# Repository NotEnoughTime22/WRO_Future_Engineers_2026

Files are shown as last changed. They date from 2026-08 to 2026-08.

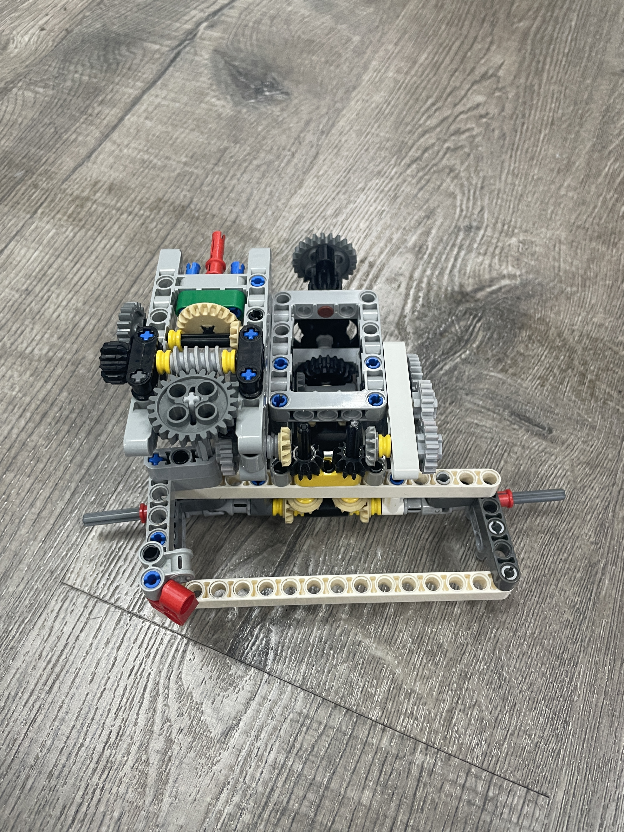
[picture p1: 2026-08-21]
Photos/First Prototype/Front side of first prototype chassis.JPG

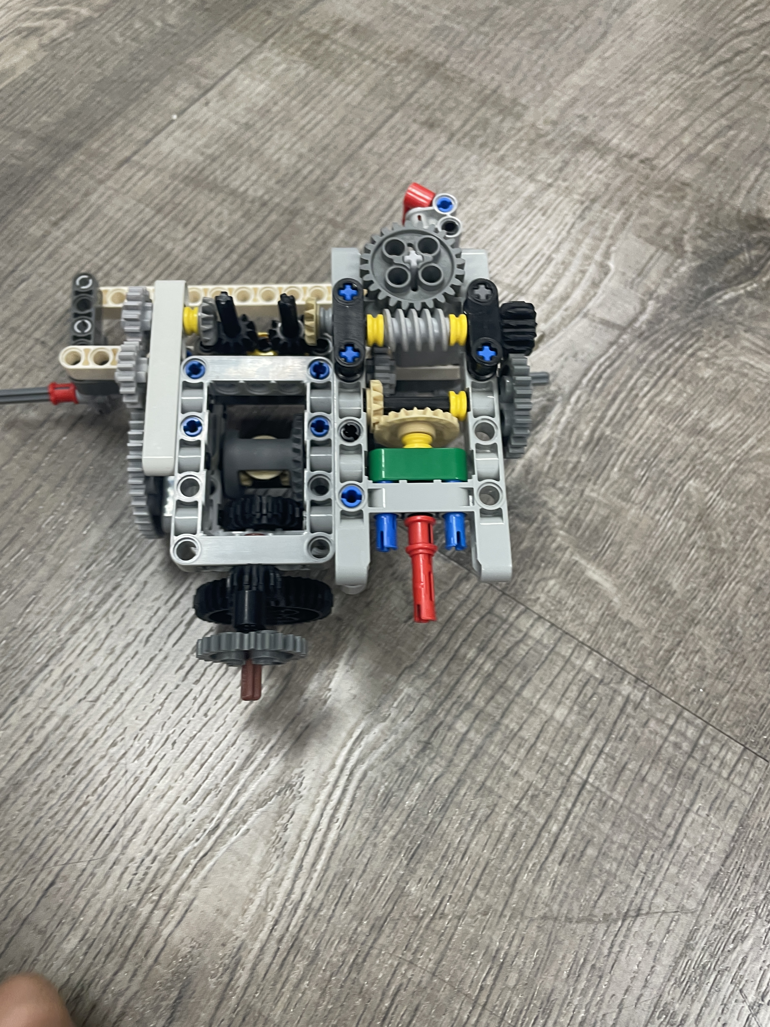
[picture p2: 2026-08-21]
Photos/First Prototype/Back side of first prototype chassis.JPG

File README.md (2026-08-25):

# SSTitans

This repository contains the complete engineering materials for SSTactical's self-driving vehicle competing in the WRO Future Engineers 2026 season. It documents the hardware design, software architecture, machine learning pipeline, and control algorithms that enable the robot to navigate an autonomous track, detect gaps, perform parallel parking, and recognise visual markers.

## Repository Structure

* `Codes/` contains the Arduino sketches that run on the EvolutionX1 microcontroller. `Open_Code.ino` implements the primary autonomous driving logic including PD heading control, gap navigation, square traversal, and parallel parking. `Obstacle_code.ino` extends the gap navigation with colour-based obstacle avoidance using MaixCam detections.
* `Documents/` contains the official WRO Engineering Journal (PDF) maintained by the team throughout the season, documenting design decisions, testing results, and progress.
* `Libraries/` contains the custom C++ libraries written to interface with the vehicle hardware. These include motor control, sensor abstraction, pin mapping, and the core Evo system library.
* `ML/` contains the machine learning pipeline for visual object detection running on the MaixCam. This includes the trained YOLOv5 model, the inference script, training annotations, and configuration files.
* `Models/` contains 3D printable STL files for custom mounts and brackets used in the vehicle construction.
* `Photos/` contains documentation photographs of the team and the vehicle at various stages of development.
* `Videos/` contains demonstration videos of the robot performing both the open and challenge runs of the competition. 

## Hardware Components

The vehicle is built around the following electromechanical components:

| Component | Model | Quantity | Purpose |
| :--- | :--- | :--- | :--- |
| Microcontroller | EvolutionX1 (ESP32-S3) | 1 | Central processing unit running all control logic |
| Drive Motor | EvoMotor300 | 1 | Provides propulsion via rear axle |
| Steering Servo | GeekServo 360 Grey | 1 | Controls front wheel steering angle |
| Camera | MaixCam | 1 | Runs YOLOv5 inference for visual detection |
| Distance Sensors | VL53L0X (Time of Flight) | 4 | Obstacle and gap detection (front, back, left, right) |
| Compass / IMU | BNO055 | 1 | Provides absolute heading for navigation |
| I2C Multiplexer | TCA9548A | 1 | Routes I2C signals to multiple sensors on shared bus |
| IO Expander | SX1506 | 1 | Provides PWM outputs for motor control |
| Battery | Panasonic NCR18650B | 2 | Power supply for all electronics |

### Wiring and Pin Assignments

The EvolutionX1 exposes four Lego sensor ports (S1 through S4) and four motor ports (M1 through M4). The pin mapping is defined in `Libraries/X1pins (1).h`. Each sensor port provides two GPIO pins for UART or I2C communication. Each motor port provides two PWM channels through the SX1506 IO expander and two tachometer pins for quadrature encoder feedback.

The I2C bus is multiplexed through the TCA9548A with the following channel assignments:

| I2C Channel | Device |
| :--- | :--- |
| 0 | IMU (BNO055) on I2C1 |
| 1 | ToF Right (VL53L0X) on I2C2 |
| 2 | ToF Left (VL53L0X) on I2C3 |
| 3 | ToF Front (VL53L0X) on I2C4 |
| 4 | ToF Back (VL53L0X) on I2C5 |
| 5 | SX1506 IO Expander |
| 6 | MPU9250 (reserved) |
| 7 | SSD1306 OLED Display |

The MaixCam communicates with the microcontroller over I2C5 at address `0x24`, transmitting detected object data in a binary protocol.

## Software Architecture

The software is split across two processors.

### Microcontroller (EvolutionX1 / ESP32-S3)

The main firmware is written in C++ using the Arduino framework. The entry point is `Codes/Open_Code.ino`. The architecture consists of:

**Hardware Abstraction Layer** provided by the custom libraries in `Libraries/`:

* `Evo (1).h / .cpp` wraps the core EVO singleton class. It manages I2C bus initialisation, TCA9548A channel selection, battery voltage reading via the BQ25887 charger IC, buzzer tone generation, and SSD1306 OLED display output.
* `EV3 Motor (1).h / .cpp` implements the `EV3Motor` class. Each motor instance is bound to a port (M1 to M4) and controls direction via the SX1509 IO expander PWM outputs. Encoder feedback is read through the `ESP32Encoder` library. A FreeRTOS background task runs a proportional controller for braking and target-position modes. The motor supports four states: RUN (continuous speed), TARGET (drive to encoder position), BRAKE (active hold), and COAST (passive stop).
* `VL53L0X Library.h / .cpp` wraps the Adafruit VL53L0X driver. Each sensor is assigned to an I2C multiplexer channel. The `getDistance()` method selects the correct channel, performs a ranging measurement, and returns the distance in millimetres. Readings below 10mm are treated as invalid and replaced with a sentinel value of 8191.
* `EV3 Sensor Port (1).h / .cpp` implements the Lego UART sensor protocol. It handles sensor discovery, mode negotiation, baud rate switching, and continuous data streaming using a dedicated FreeRTOS task pinned to core 0.
* `X1pins (1).h` defines all GPIO pin mappings, I2C addresses, and enumerations for motor ports, sensor ports, and I2C channels.

**Control Layer** implemented directly in `Open_Code.ino`:

The control layer uses a PD (Proportional-Derivative) controller to maintain heading while driving. The key parameters are:

* `KP_HEADING = 1.7` proportional gain
* `KD_HEADING = 0.0` derivative gain (currently disabled)
* `DRIVE_SPEED = 3000` constant motor speed in encoder degrees per second
* `STRAIGHT_DEGREES = 6000` encoder degrees per square edge
* `SERVO_RATIO = 2.33` maps wheel degrees to servo degrees
* `MAX_WHEEL_ANGLE = 35` maximum steering angle in degrees

The `applySteering()` function converts a desired wheel angle into a servo command by multiplying by the servo ratio and offsetting from the centre position (180 degrees). The result is constrained to the 0 to 360 degree range of the GeekServo 360.

Heading is read from the BNO055 IMU using `readHeadingSafe()`, which performs two attempts and falls back to the last valid reading if both fail. This prevents sudden heading jumps from corrupting the controller. All headings are normalised to the 0 to 360 degree range, and heading error is computed as the shortest angular distance (clamped to plus or minus 180 degrees).

The `snapHeading45()` function rounds any heading to the nearest 45 degree increment (0, 45, 90, 135, 180, 225, 270, 315). This is used throughout the navigation logic to ensure the robot only drives along axis-aligned and diagonal directions, which simplifies the track geometry.

### Driving Modes

The firmware implements three primary driving behaviours, selected in `setup()`:

**1. Square Traversal (`squareWithPDSteering`)**

Drives a square path of a given number of sides. The robot holds a constant speed and uses PD steering to maintain the current target heading. After travelling `STRAIGHT_DEGREES` encoder counts, the target heading is rotated by 90 degrees and snapped to the nearest 45 degree increment. The process repeats until all sides are completed, then the motor brakes and the servo centres.

**2. Gap Navigation (`driveAndTurnOnGaps`)**

This is the primary autonomous driving mode for the competition track. The robot drives forward while continuously monitoring the left and right Time of Flight sensors. Gap detection uses a `ToFSmoother` struct that maintains a 5-sample rolling average filter on each sensor. A gap is confirmed when either:

* The filtered distance exceeds `GAP_THRESHOLD_MM` (650mm), or
* The distance increases by more than 150mm between consecutive readings

Both conditions must persist for `GAP_CONFIRM_SAMPLES` (4) consecutive readings to avoid false triggers. A cooldown timer of `TURN_COOLDOWN_MS` (700ms) prevents multiple turns at the same intersection.

When a gap is confirmed, the robot computes the new target heading by rotating 90 degrees left or right. If gaps are detected on both sides, the robot turns toward the side with the larger clearance (plus a 100mm margin). The turn is executed while the motor continues running, using IMU heading control. The turn completes when the heading error drops below `TURN_COMPLETE_ERROR` (8 degrees). After turning, the robot drives forward for `POST_TURN_DISTANCE` (1000 encoder degrees) to clear the intersection before resuming gap detection.

A front-facing safety check stops the motor if an obstacle is detected within 80mm during a turn, then immediately resumes driving after a 150ms pause.

**3. Parallel Parking (`parallelParkWithTOF`)**

Executes a multi-phase parallel parking manoeuvre using all four ToF sensors:

* Phase 1: If the right sensor reads more than 100mm, the robot is too far from the wall. It angles 45 degrees toward the wall and drives in small increments until the diagonal distance (right distance multiplied by sin(45)) drops below 100mm.
* Phase 2: The robot turns to run parallel to the wall and drives forward until the front sensor reads less than 200mm.
* Phase 3: The robot angles 45 degrees away from the wall and drives a fixed distance of 1000 encoder degrees to pull alongside the parking spot.
* Phase 4: The robot straightens and drives forward until the front sensor reads less than 100mm, then completes with a final 200-degree adjustment.

**4. Obstacle Avoidance with Colour Detection (`driveAndTurnOnGapsWithColourAvoidance`)**

The `Obstacle_code.ino` sketch extends the gap navigation system with colour-based obstacle avoidance. This mode integrates MaixCam YOLO detections with the ToF-based gap navigation to avoid coloured obstacles (green and red objects) placed on the track.

The colour avoidance system uses a finite state machine with six states:

* `COLOR_NONE`: Normal driving mode. The robot monitors for colour detections while performing gap navigation.
* `COLOR_TURN_OUT`: When a coloured object is detected, the robot turns 45 degrees away from the obstacle (left for green, right for red) while continuing to drive forward.
* `COLOR_DRIVE_OUT`: After completing the turn, the robot drives forward until the object is no longer detected for 350ms AND the robot has travelled at least 500 encoder degrees away from the obstacle.
* `COLOR_TURN_BACK`: The robot turns 90 degrees back toward the original heading to align parallel to the track.
* `COLOR_DRIVE_BACK`: The robot drives forward the same distance it travelled outward to return to the original path.
* `COLOR_RETURN_HEADING`: The robot turns back to the original heading and resumes normal gap navigation.

The system validates detections using three criteria: the object class must be green (ID 1) or red (ID 2), the bounding box area must exceed 100 pixels, and the confidence score must be above 0.50. Objects detected too low in the image (y-center above 160 pixels) are ignored to avoid false positives from distant obstacles.

A retrigger cooldown of 1000ms prevents the robot from repeatedly avoiding the same object. The colour avoidance behaviour takes priority over gap turns, ensuring the robot always responds to obstacles before considering intersection navigation.

### MaixCam (Vision Processor)

The MaixCam runs a Python script (`ML/main.py`) that performs real-time object detection using a YOLOv5 model. The model was trained on 147 (Based on 25 Aug, we are still training, final model should include 1000+) annotated images and compiled into a `.mud` and `.cvimodel` format for the Maix hardware accelerator.

The detection loop operates as follows:

1. Capture a frame from the camera at the model's input resolution (224x224, 3 channels).
2. Run YOLOv5 inference with a confidence threshold of 0.5 and IoU threshold of 0.45.
3. If objects are detected, encode their bounding boxes (x, y, width, height, class ID, confidence score) into a binary payload using the `encode_objs()` function. Each object occupies 14 bytes in the payload.
4. Transmit the payload to the EvolutionX1 microcontroller over I2C5 at address `0x24`.
5. Draw red bounding boxes and labels on the live preview displayed on the MaixCam screen.

The model configuration in `ML/app.yaml` identifies it as "Detector 317447" version 1.0.0, generated by MaixHub. The training report in `ML/report.json` shows the model converged to a final loss of approximately 0.68 over 100 epochs with a learning rate schedule decaying from 0.001 to 0.0001.

## 3D Printed Models

The `Models/` directory contains two STL files for custom mechanical parts:

* `EVO Brick Model.stl` is the enclosure case that holds the EvolutionX1 microcontroller brick in place on the chassis.
* `VL53L0X Lego Mount Model.stl` is a bracket that mounts a VL53L0X Time of Flight sensor to the Lego Technic frame at the correct height and angle.

## Setup Instructions

### Prerequisites

* Arduino IDE with ESP32 board support installed
* Board selection set to ESP32-S3
* USB cable capable of data transfer

### Library Installation

All libraries must be installed before compiling the code.

1. Install each `.zip` file found in the external libraries folder by opening the Arduino IDE, navigating to Sketch, then Include Library, then Add .ZIP Library, and selecting each archive.
2. Install the custom Evo library by selecting the `Evo.zip` archive through the same Add .ZIP Library menu.
3. All libraries are required for the code to compile and run correctly.

### Uploading the Firmware

1. Open `Codes/Open_Code.ino` in the Arduino IDE.
2. Verify that the board is set to ESP32-S3 under the Tools menu.
3. Select the correct serial port for the EvolutionX1.
4. Click Upload to flash the firmware to the microcontroller.

### Deploying the MaixCam Model

1. Copy the contents of the `ML/` directory to the MaixCam's SD card or internal storage.
2. Ensure the `model_317447.mud` and `model_317447.cvimodel` files are present alongside `main.py`.
3. Power on the MaixCam and the script will begin executing automatically.

## Pre-Run Checklist

### Software Verification

* Confirm the Arduino IDE board selection is set to ESP32-S3.
* Verify that all sensors have been calibrated for the competition venue lighting and surface conditions.
* Ensure the MaixCam model is loaded and the I2C address matches the microcontroller configuration.

### Hardware Inspection

* Check that every wire is connected to the correct terminal and that no loose connections exist.
* Test all four ToF sensors for consistent readings and replace any that return erratic values.
* Verify the IMU provides stable heading readings without drift.
* Inspect all structural parts for tightness and replace any cracked or weakened components.
* Ensure the wheels are securely fastened to the axles and do not wobble.
* Test the steering servo for smooth operation across the full 0 to 360 degree range.
* Confirm the battery voltage is above the minimum operating threshold.

### Robot Placement

* Place the robot on the track in a straight orientation aligned with the intended starting direction.
* The initial heading is captured during setup and used as the reference for all subsequent navigation.

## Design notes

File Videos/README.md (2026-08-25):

This folder contains videos of the robot performing the open and challenge stages of the category

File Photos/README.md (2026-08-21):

This folder contains pictures of the robot from first prototype to final design.

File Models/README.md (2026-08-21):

This is a collection of 3d models used for 3d printing during this project.

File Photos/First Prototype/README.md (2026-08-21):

This folder of images is dedicated to the first prototype and its variations.

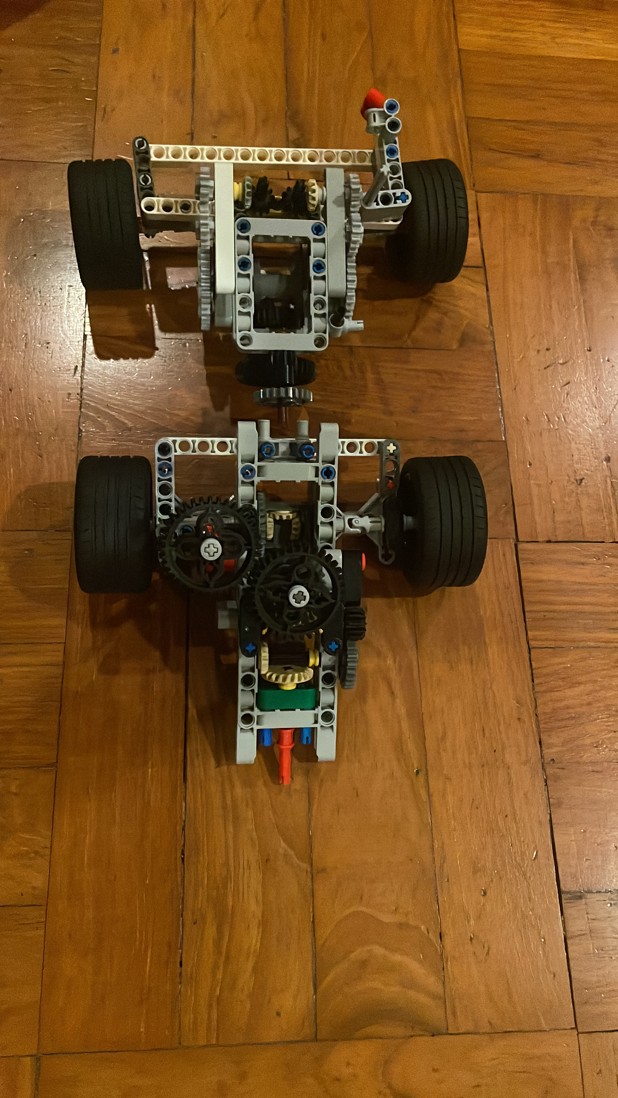
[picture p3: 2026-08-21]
Photos/First Prototype/Comparison of first and second(unfinished) chassis.jpg

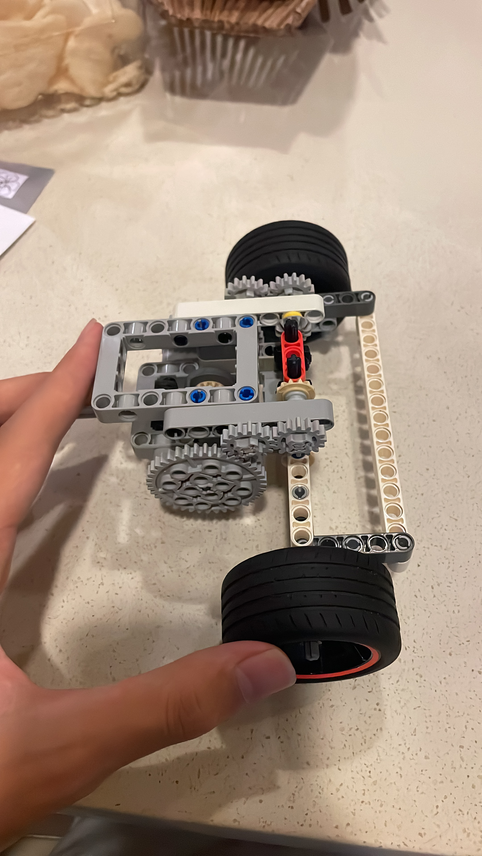
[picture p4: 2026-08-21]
Photos/First Prototype/Right side of unfinished first prototype chassis.jpg

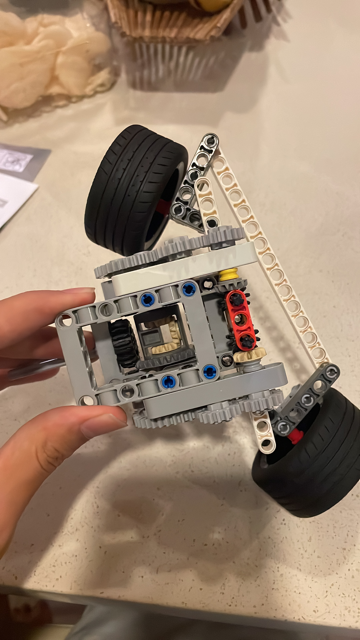
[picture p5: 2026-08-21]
Photos/First Prototype/Maximum turn angle of unfinished first prototype chassis.jpg

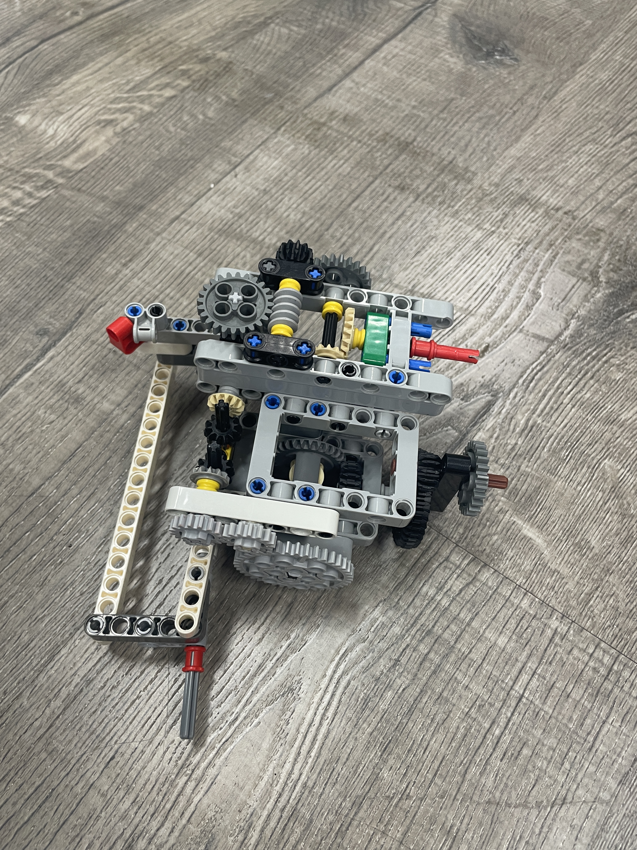
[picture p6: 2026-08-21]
Photos/First Prototype/Left side of first prototype chassis.JPG

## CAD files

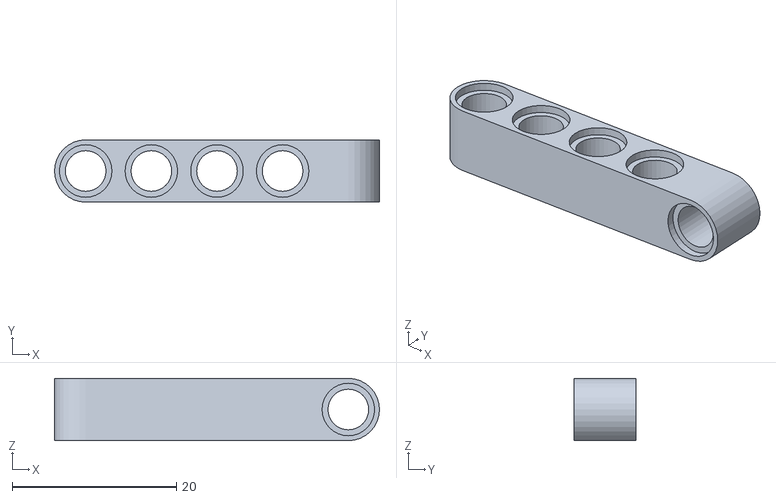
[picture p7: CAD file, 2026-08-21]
Models/Failed Files/weird_5_hole.stl
39.6 x 7.60 x 7.60

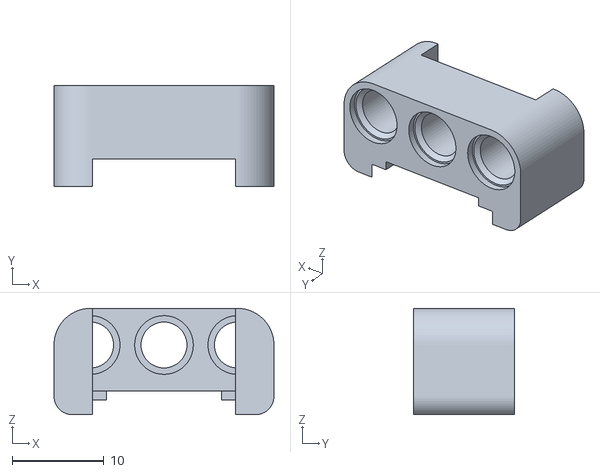
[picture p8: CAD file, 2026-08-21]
Models/VL53L0X Lego Mount Model.stl
24.0 x 11.0 x 11.6

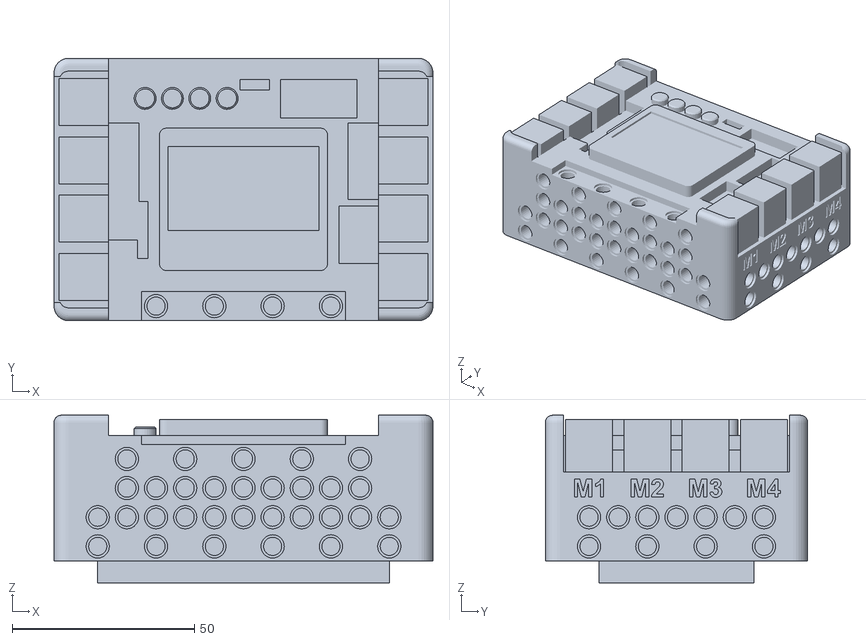
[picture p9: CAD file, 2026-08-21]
Models/EVO Brick Model.stl
104.0 x 72.0 x 46.0

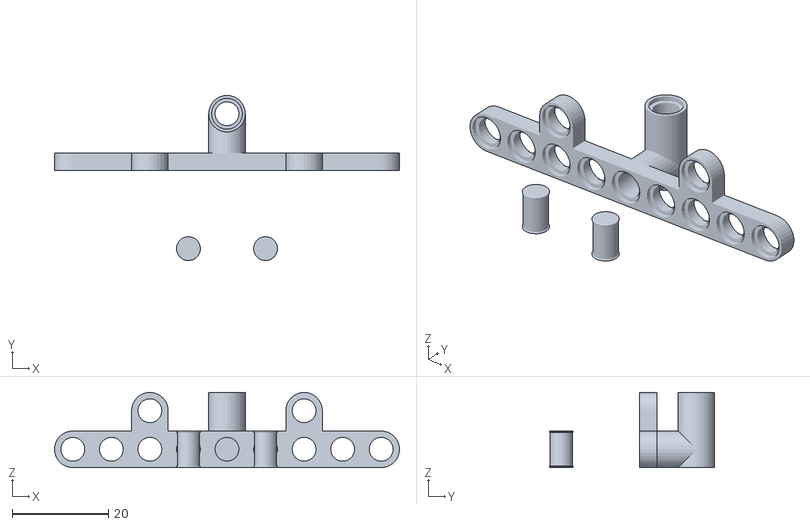
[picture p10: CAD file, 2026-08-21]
Models/Failed Files/weird_axel_thingy.stl
71.6 x 34.3 x 15.6

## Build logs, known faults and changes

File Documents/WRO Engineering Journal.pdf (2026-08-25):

# WRO Engineering Journal

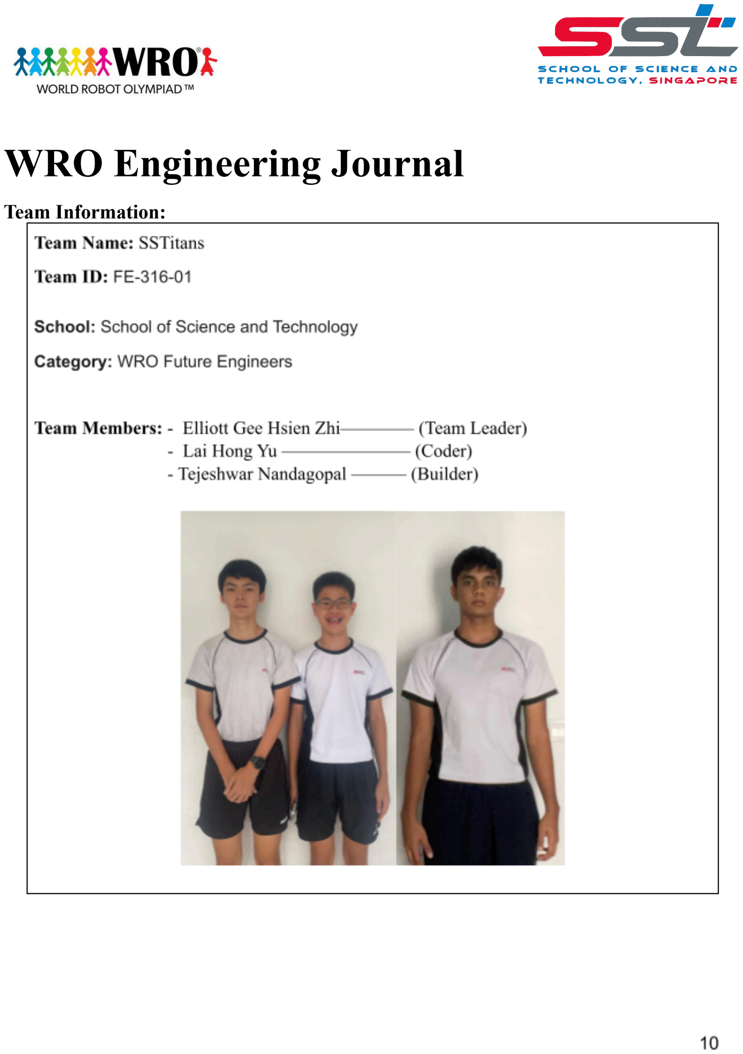
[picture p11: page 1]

Team Information:

## Contents

- Hardware Overview
- Drivetrain
- Components
- Strategy
- Code

### Hardware Overview

Table of Components used by the robot:

Part Name | Model | Quantity | Others
GeekServo | GeekServo360Grey | 1
EvoMotor | EvoMotor300 | 1
Time of Flight | VL53L0X | 4
Camera | MaixCam | 1
Microcontroller | ESP32S3 | 1
12C Microplexer | TCA9548A | 1
IO Multiplexer | SX1506 | 1
IMU | BNO055 | 1
Battery | NCR18650B | 2

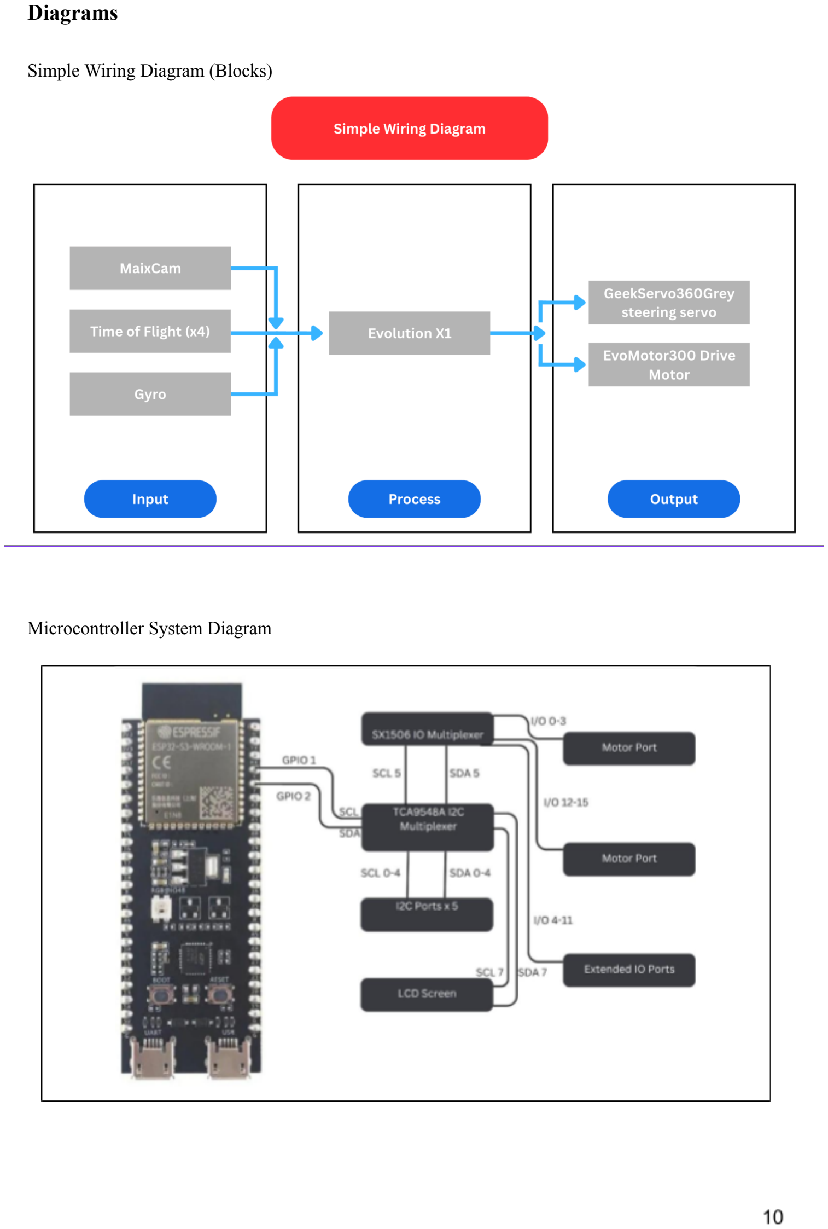
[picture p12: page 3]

Diagrams

Simple Wiring Diagram (Blocks)

Microcontroller System Diagram

### Drivetrain

Chassis Design
To build our chassis, we used LEGO parts, as they were light yet able to withstand the weight of the EvolutionX1 Brick. LEGO parts made it easy for us to prototype our models, as we built numerous prototype chassis before landing on the final design. We also made use of 3D-modelled holders for our sensors with LEGO compatibility; thus, it is easy to install and replace. We also designed it with a tight turning circle in mind, and as such we chose a 4WD & 4-wheel steering chassis.

Here are some photos of the vehicle:

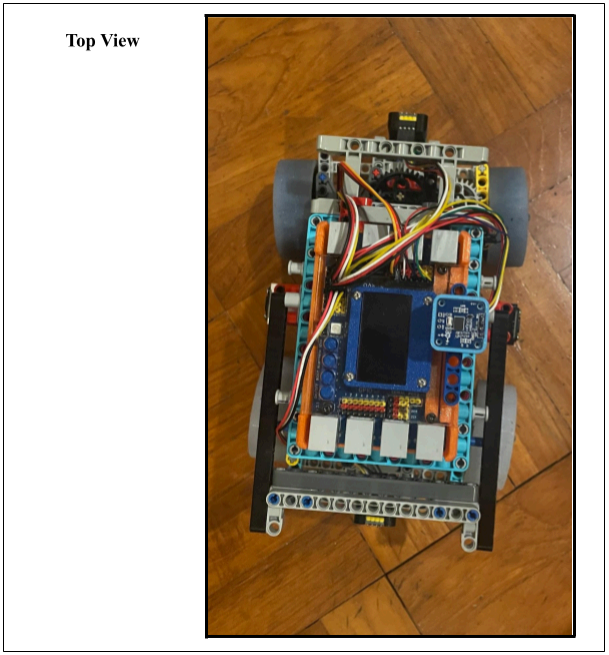
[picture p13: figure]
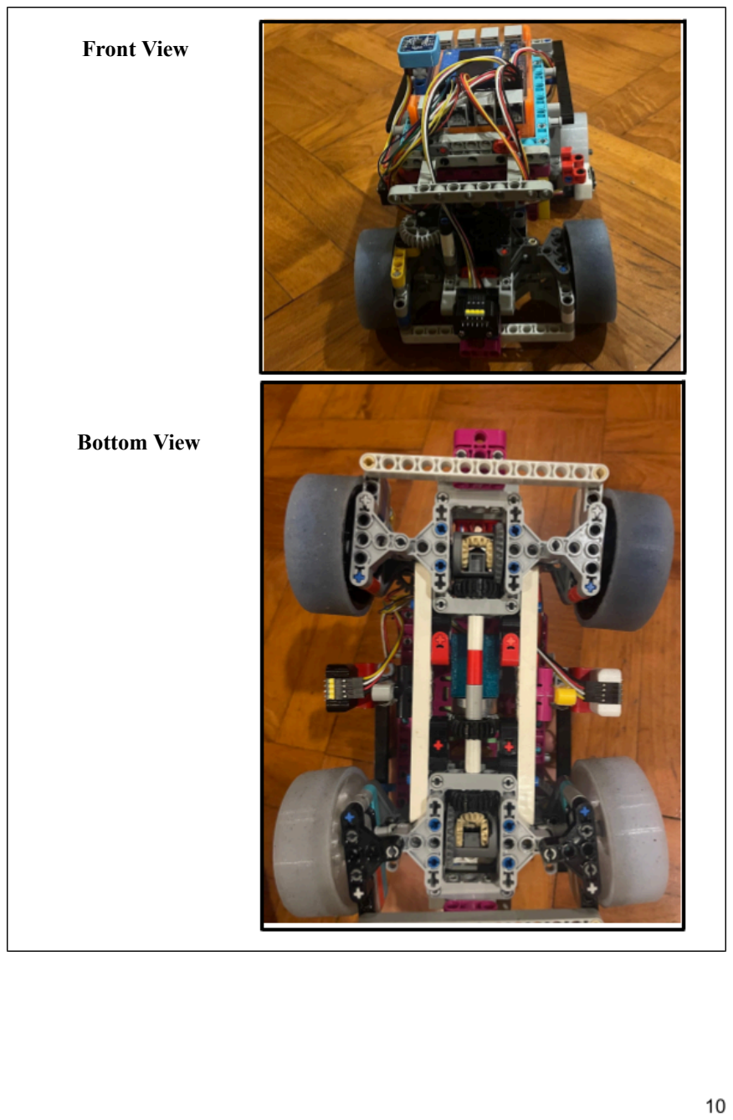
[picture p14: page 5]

Front View

Bottom View

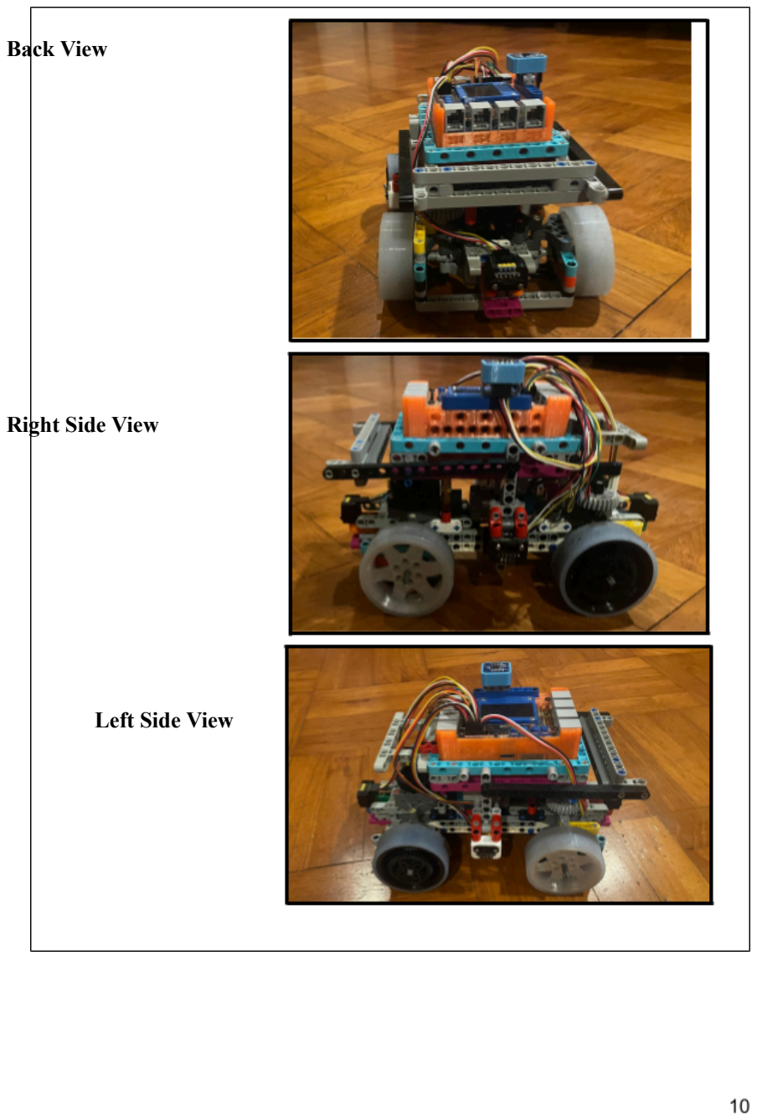
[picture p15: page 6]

Back View

Right Side View

Left Side View

Motors

The motors we have chosen to use as a part of our bot are the EvoMotor300, which has a balance of speed and torque compared to the Evomotor100, which has more torque at the cost of speed. The other reasons we chose this motor were the size limit and the navigation challenge. We felt that having a smaller bot would be easier to navigate through the blocks, so we chose to go for compactness.

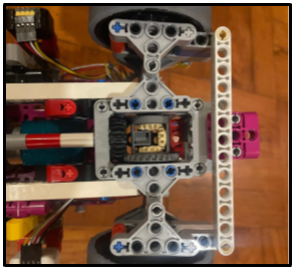
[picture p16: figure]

Differential

The drive motor is connected to two differential gears at the bottom of the bot. Having a differential allows the robot's wheel to turn at different speeds, which is crucial to achieving smooth turning.

Steering

For our steering, our team has chosen a geared ackermann steering mechanism, which is a common steering mechanism used by many people in the world, while we also wanted to go for a design of a 4 wheel drive and 4 wheel steering car. This 4 wheel steering system allows us to have a much tighter turning circle, giving us extra manoeuvrability. Moreover, the ackermann steering geometry allows the inner wheels to turn more than the outer ones, providing better and more precise turning. This is due to the inner wheels needing to make a tighter arc than the outer wheels.

### Components

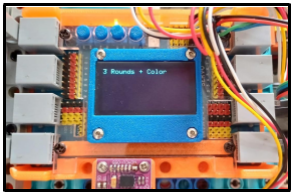
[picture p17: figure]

Evolution X1

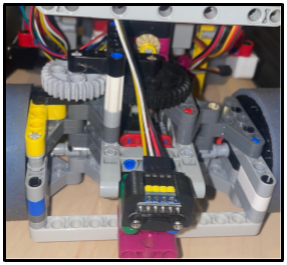
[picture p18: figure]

The Evolution X1 Controller Platform is a versatile and powerful development board designed to seamlessly integrate with the LEGO EV3 Mindstorms ecosystem. Built around the robust ESP32-S3 microcontroller, this platform offers a unique combination of connectivity, performance and flexibility. Below are the key features of Exolution X1, and these are some reasons why we chose it.

Key Features:

- EV3 Mindstorms Compatibility
The controller is equipped with specialised connectors that enable seamless connection and control of the EV3 Mindstorms motors and sensors. This compatibility allows us to utilise the existing EV3 components while taking advantage of the advanced features of the ESP32-S3. Although we did not use these features in this robot, they are useful to have.
- Extended GPIO Pinouts
In addition to EV3 connectors, the platform offers an extensive set of GPIO pinouts. These pinouts allow us to connect various third-party sensors and actuators, broadening the scope for customisation and experimentation.
- Powerful ESP32-S3 Microcontroller
The platform is powered by the ESP32-S3 microcontroller, which stands out for its great performance, energy efficiency, and versatile features. It offers dual-core processing, built-in Wi-Fi and Bluetooth, and plenty of peripheral options, making it a flexible and reliable choice for all kinds of applications.
- User-Friendly Development Environment
The platform supports popular development environments such as Arduino, MicroPython, and Espressif's IDF, providing a user-friendly and familiar programming experience. It is also backed by comprehensive documentation and strong community support, enhancing the development process.

Time of Flight (ToF)

A Time of Flight (ToF) sensor measures distance by emitting a light signal, typically infrared, and calculating the time it takes for the signal to travel to an object and return. This time is then used to determine the precise distance to the object.

We selected it primarily for its precise distance measurement capabilities. ToF sensors can measure distances with exceptional accuracy—often down to the millimetre—making them ideal for applications that demand precise measurements. They can also measure over a wide range, from just a few centimetres to several metres, depending on the model.

Another advantage is their fast response time. ToF sensors deliver rapid measurements, enabling real-time functions such as gesture recognition, object tracking, and obstacle detection. Since they operate at the speed of light, they can perform distance calculations extremely quickly, providing low-latency data essential in dynamic environments.

Finally, ToF sensors are easy to integrate. They typically use standard communication protocols like I²C or SPI, making them straightforward to connect with microcontrollers and other digital systems. Some models even feature built-in processing, simplifying their use in more complex implementations.

Gyroscope (IMU)

For our gyroscope, we chose the BNO-055. This is a compact 9-axis sensor that combines an accelerometer, gyroscope, magnetometer, and a 32-bit microcontroller with sensor fusion software.

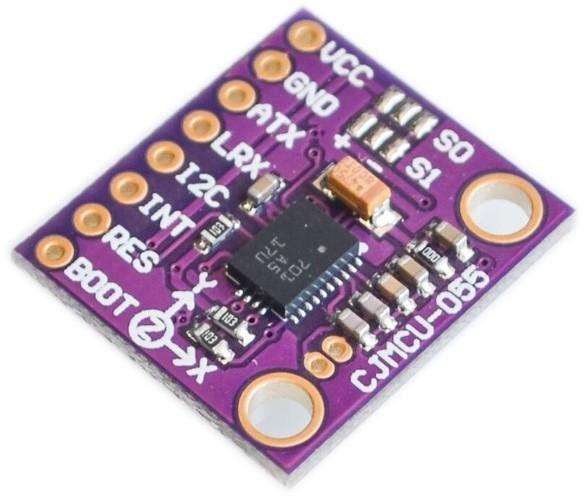
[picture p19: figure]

Our main reasons for choosing this component are, firstly, that by integrating an accelerometer, gyroscope, magnetometer, and microcontroller into a single module, it reduces the need for multiple separate sensors, thus reducing the overall data processing requirements and saving memory. Secondly, its compact form also minimises physical space usage, making it ideal for our compactly designed robot.

MaixCam Camera

The MaixCAM is a compact, Linux-based AI vision camera that can run real-time computer-vision models directly on its onboard processor. It supports object detection with models such as YOLOv5, as well as traditional vision functions including colour/blob detection and QR-code recognition. This allows the robot to analyse camera input without relying entirely on the main microcontroller.
We selected the MaixCAM because of its high performing specifications in a small form factor and its ability to perform onboard object detection, which supports obstacle identification and target recognition during the challenges. It has a CPU core of 1GHz and has a NPU that can support up to 1TOPS. Its built-in screen also makes it easier to test the camera feed and verify detections while developing the robot. The compact camera-board form factor further simplifies installation on the robot.
For our project, we trained our own custom vision model using images relevant to our challenge, rather than relying only on the default object categories. The model was then deployed to the MaixCAM, enabling it to recognise the specific objects or visual targets required by our robot. Sipeed supports this workflow through MaixHub or an offline pipeline: prepare and annotate a dataset, train a compatible model, export it to ONNX, convert it to MaixCAM’s supported model format, and run it using MaixPy.

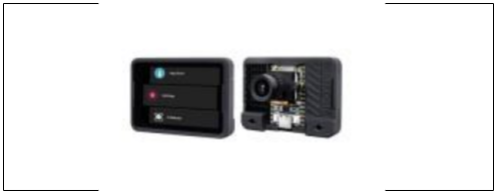
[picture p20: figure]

### Strategy

Preliminary Round Flowchart

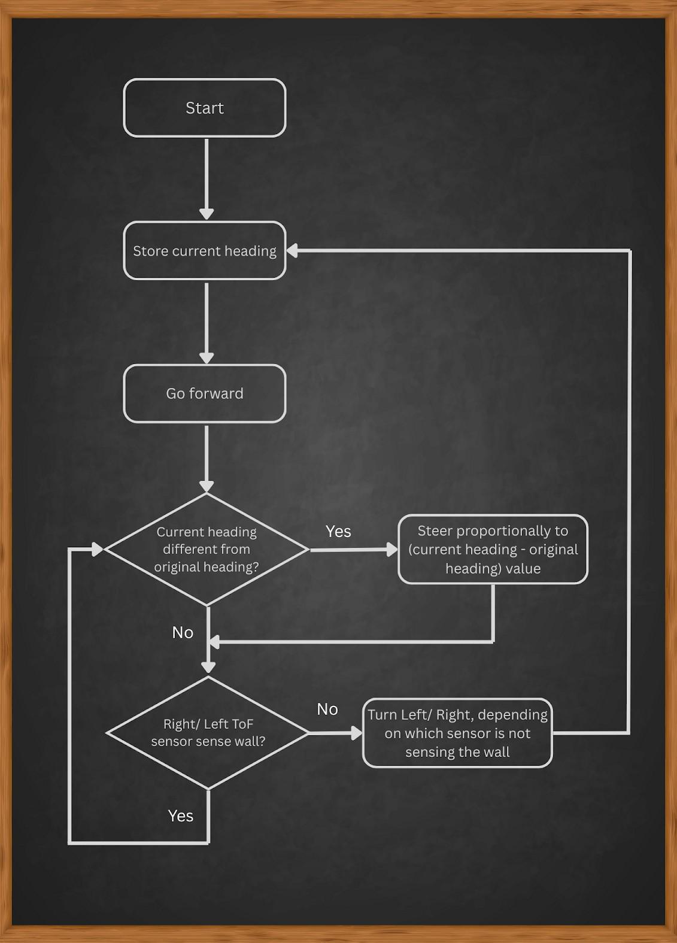
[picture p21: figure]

Figure 1

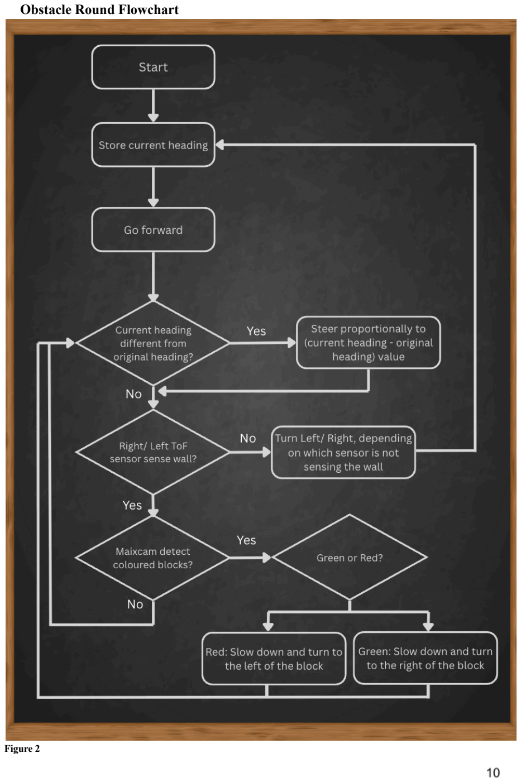
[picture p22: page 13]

Obstacle Round Flowchart

Figure 2

### Figure 1 Explanation

During the preliminary rounds, our robot follows a simple flowchart. The first thing the robot does is set the heading when it boots up to be 0º. The robot then drives forward using PD heading tracking. The robot first takes the current heading, and calculates the normalised error from 0º or 360º, and adjusts the steering proportionally. This allows the robot to effectively track the heading, travelling in a perfectly straight line. When the left or right TOFs detect a gap for more than a set value of TOF readings, it will turn in that direction, as the robot knows there is a gap for it to drive into. With this, it completes the circuit.

### Figure 2 Explanation

During the preliminary rounds, the robot drives autonomously using four TOF sensors, an IMU, a steering servo, and a drive motor. At startup, it reads its current IMU heading and sets the nearest 45° direction as its target. It then drives forward while using proportional heading control to correct steering errors and maintain a straight path.

The left and right TOF sensors detect gaps in the track. A gap is confirmed only after several consecutive readings above the distance threshold, reducing false detections. The robot turns toward the detected opening, or toward the larger opening if both sides detect a gap. It turns by 90°, then drives forward a fixed encoder distance to clear the junction before searching for the next gap.

The MaixCAM can also detect red and green objects. When a valid object is detected, colour avoidance overrides normal gap navigation. The robot turns 45° away from the object, right for red and left for green, drives past it, turns back toward its original path, and returns to its original heading. This allows the robot to avoid coloured obstacles while still continuing around the course.

### Code

In order to make sure everyone on the team could understand the code, we focused on keeping it readable and easy to follow. Even though the code for the self-driving robot is complex, we broke the code into smaller parts and added clear labels.

We kept the code clean by doing the following:

- Wrote comments at important parts of the code to explain what each section does.
- Used libraries and separate classes to keep the main code simple and less crowded.
- Gave variables and functions clear and meaningful names so it’s easy to know what they do.

-End-

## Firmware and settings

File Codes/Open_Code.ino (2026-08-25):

#include "Evo.h"


// Hardware setup
EVOX1 evo;


// IMU on I2C1, TOF on I2C. right sensor on i2c port 2, back sensor on port 5, left sensor on port 3, front sensor on port 4
EvoIMU bno(I2C1);
EvoTOF tofRight(I2C2);
EvoTOF tofBack(I2C5);
EvoTOF tofLeft(I2C3);
EvoTOF tofFront(I2C4);
// Motor on M1
EvoMotor driveMotor(M1, EVOMotor300, true);


// Servo on S1
EvoServo steerServo(SERVO1, GeekServo360Grey);



// Motion settings
const long STRAIGHT_DEGREES = 6000; // encoder degrees per edge
const int DRIVE_SPEED = 3000; // constant drive speed


const float SERVO_RATIO = 2.33f; // 2.33° servo = 1° wheel
const int SERVO_CENTER = 180;
const int MAX_WHEEL_ANGLE = 35; // max wheel angle


// Heading control (PD)
const float KP_HEADING = 1.7f; // proportional gain
const float KD_HEADING = 0.0f; // derivative gain


float targetHeading = 0.0f; // desired absolute heading


// IMU state to keep heading valid
float lastValidHeading = 0.0f;
// ---------- Gap navigation settings ----------

const int GAP_THRESHOLD_MM = 650;
const int GAP_CONFIRM_SAMPLES = 4;
const int GAP_DIRECTION_MARGIN_MM = 100;

const long POST_TURN_DISTANCE = 1000;
const unsigned long TURN_COOLDOWN_MS = 700;
const int TURN_COMPLETE_ERROR = 8;

struct ToFSmoother {
    static const int SIZE = 5;

    int samples[SIZE];
    int index;
    int count;
    int lastGood;

    ToFSmoother() : index(0), count(0), lastGood(4000) {}

    int update(int raw) {
        int value = cleanTof(raw, lastGood);
        lastGood = value;

        samples[index] = value;
        index = (index + 1) % SIZE;

        if (count < SIZE) count++;

        long sum = 0;
        for (int i = 0; i < count; i++) {
            sum += samples[i];
        }

        return (int)(sum / count);
    }
};

ToFSmoother leftGapFilter;
ToFSmoother rightGapFilter;
ToFSmoother frontGapFilter;


// Keeps the car pointed at targetHeading while driving.
void headingDriveStep() {
    float heading = readHeadingSafePark();
    float err = headingError(heading, targetHeading);

    unsigned long now = millis();
    float dt = (now - lastParkTime) * 0.001f;

    if (dt <= 0.0f) dt = 0.001f;

    float dErr = (err - lastParkErr) / dt;

    float wheelAngle = -(KP_HEADING * err + KD_HEADING * dErr);

    applySteering(wheelAngle);

    lastParkErr = err;
    lastParkTime = now;
}

// ---------- Utility ----------


// Keep existing normalize and headingError


float normalize(float a) {
    while (a < 0) a += 360;
    while (a >= 360) a -= 360;
    return a;
}


float headingError(float current, float target) {
    float e = target - current;
    if (e > 180) e -= 360;
    if (e < -180) e += 360;
    return e;
}


// NEW: snap to nearest 45 degrees to avoid off readings
float snapHeading45(float a) {
    a = normalize(a);
    // Add 22.5 then integer divide by 45 to round to nearest multiple
    int k = (int)((a + 22.5f) / 45.0f); // 0..7
    return (float)(k * 45); // 0,45,...,315
}


// Safer heading read: retries once, falls back to last good value
float readHeadingSafe() {
    float x, y, z;


    bno.getEuler(&x, &y, &z); // first try
    if (!isnan(x) && !isinf(x) && x >= 0 && x < 360) {
        lastValidHeading = normalize(x);
        return lastValidHeading;
    }
  

    // One retry
    delay(2);
    bno.getEuler(&x, &y, &z);
    if (!isnan(x) && !isinf(x) && x >= 0 && x < 360) {
        lastValidHeading = normalize(x);
        return lastValidHeading;
    }


    // Fall back: return last valid heading to avoid crazy jumps
    return lastValidHeading;
}


void printStatus(const char* line0, const char* line1, float heading = -1000.0f) {
    evo.clearDisplay();
    evo.writeLineToDisplay(line0, 0, true, true);
    evo.writeLineToDisplay(line1, 1, true, false);
    if (heading > -999.0f) {
        evo.writeToDisplay("H:", 0, 32);
        evo.writeToDisplay((int)heading, 20, 32);
        evo.writeToDisplay(" T:", 60, 32);
        evo.writeToDisplay((int)targetHeading, 85, 32);
    }
    evo.drawDisplay();
}


void applySteering(float wheelAngle) {
    wheelAngle = constrain(wheelAngle, -MAX_WHEEL_ANGLE, MAX_WHEEL_ANGLE);


    float servoOffset = wheelAngle * SERVO_RATIO; // wheel -> servo
    float servoCmd = SERVO_CENTER + servoOffset;


    servoCmd = constrain(servoCmd, 0, 360); // GeekServo 360 range


    steerServo.write((int)servoCmd);
}


int getFrontDist() { return tofFront.getDistance(); }
int getBackDist() { return tofBack.getDistance(); }
int getLeftDist() { return tofLeft.getDistance(); }
int getRightDist() { return tofRight.getDistance(); }


// PD steering based on IMU 
float lastParkErr = 0.0f;
unsigned long lastParkTime = 0;


float readHeadingSafePark() {
    float x, y, z;
    bno.getEuler(&x, &y, &z);
    if (!isnan(x) && !isinf(x) && x >= 0 && x < 360)
    return normalize(x);
    return targetHeading; // fall back
}


// Drive with heading PD for a signed encoder distance
void headingTrack(long degrees, float targetHeadingIn) {
    // snap the target given to this function
    float targetHeading = snapHeading45(targetHeadingIn);


    long startPos = driveMotor.getAngle();
    int dir = (degrees >= 0) ? 1 : -1;
    long targetDelta = labs(degrees);


    driveMotor.run(dir * DRIVE_SPEED);


    lastParkErr = 0.0f;
    lastParkTime = millis();


    while (true) {
        long currentPos = driveMotor.getAngle();
        long delta = labs(currentPos - startPos);
        if (delta >= targetDelta) break;


        float heading = readHeadingSafePark();
        float err = headingError(heading, targetHeading);


        unsigned long now = millis();
        float dt = (now - lastParkTime) * 0.001f;
        if (dt <= 0.0f) dt = 0.001f;
        float dErr = (err - lastParkErr) / dt;


        float wheelAngle = -(KP_HEADING * err + KD_HEADING * dErr);
        applySteering(wheelAngle);


        lastParkErr = err;
        lastParkTime = now;


        delay(10);
    }


    driveMotor.brake();
}


void headingTrackCoast(long degrees, float targetHeadingIn) {
    // snap the target given to this function
    float targetHeading = snapHeading45(targetHeadingIn);


    long startPos = driveMotor.getAngle();
    int dir = (degrees >= 0) ? 1 : -1;
    long targetDelta = labs(degrees);


    driveMotor.run(dir * DRIVE_SPEED);


    lastParkErr = 0.0f;
    lastParkTime = millis();


    while (true) {
        long currentPos = driveMotor.getAngle();
        long delta = labs(currentPos - startPos);
        if (delta >= targetDelta) break;


        float heading = readHeadingSafePark();
        float err = headingError(heading, targetHeading);


        unsigned long now = millis();
        float dt = (now - lastParkTime) * 0.001f;
        if (dt <= 0.0f) dt = 0.001f;
        float dErr = (err - lastParkErr) / dt;


        float wheelAngle = -(KP_HEADING * err + KD_HEADING * dErr);
        applySteering(wheelAngle);


        lastParkErr = err;
        lastParkTime = now;


        delay(10);
    }


    driveMotor.coast();
}


// Simple clean TOF read with clamp (mm)
int cleanTof(int raw, int lastGood) {
    if (raw <= 0) return lastGood;
    if (raw > 4000) return 4000;
    return raw;
}


void parallelParkWithTOF() {
    int frontdist = tofFront.getDistance();
    int backdist = tofBack.getDistance();
    int leftdist = tofLeft.getDistance();
    long rightdist = tofRight.getDistance();


    if (rightdist > 100){
        // too far from wall, heading track at 45 degree offset
        targetHeading = snapHeading45(readHeadingSafe() + 45.0f);
        while (0.7071067812 * rightdist > 100) {
            headingTrackCoast(10, targetHeading); // small steps
            rightdist = cleanTof(tofRight.getDistance(), rightdist);
        }
    }


    // now we are close to the wall, turn parallel and track toward the perpendicular wall until we are close enough
    targetHeading = snapHeading45(readHeadingSafe() - 45.0f);
    while(frontdist > 200) {
        headingTrackCoast(10, targetHeading); // small steps
        frontdist = cleanTof(tofFront.getDistance(), frontdist);
    }


    // now turn 45 degrees away from wall and track for set distance.
    targetHeading = snapHeading45(readHeadingSafe() - 45.0f);
    headingTrack(1000, targetHeading);


    targetHeading = snapHeading45(readHeadingSafe() + 45.0f);
    headingTrack(100, targetHeading); // short bit to straighten out


    targetHeading = snapHeading45(readHeadingSafe() + 45.0f);
    while (frontdist > 100) {
        headingTrackCoast(10, targetHeading); // small steps
        frontdist = cleanTof(tofFront.getDistance(), frontdist);
    }


    targetHeading = snapHeading45(readHeadingSafe() - 45.0f);
    headingTrack(200, targetHeading); // final bit to straighten out


    evo.writeLineToDisplay("Parked!", 0, true, true);
    evo.drawDisplay();
}


void squareWithPDSteering(int sides) {
    // Initial heading snapped to 45°
    targetHeading = snapHeading45(lastValidHeading);


    int currentEdge = 0;
    long edgeStartPos = driveMotor.getAngle();


    driveMotor.run(DRIVE_SPEED); // constant 4000 the whole time


    unsigned long lastPrint = 0;


    // PD state
    float lastError = 0.0f;
    unsigned long lastTime = millis();


    while (currentEdge < sides) {
        long currentPos = driveMotor.getAngle();
        long delta = labs(currentPos - edgeStartPos);


        // Check if this edge distance is done
        if (delta >= STRAIGHT_DEGREES) {
            currentEdge++;
            if (currentEdge >= sides) break; // square done


            // Add 90° to the desired heading and snap to 45° increments
            targetHeading = snapHeading45(targetHeading + 90.0f);


            // Start measuring distance for the next edge
            edgeStartPos = currentPos;


            // Reset derivative term when we change the target
            lastError = 0.0f;
            lastTime = millis();
        }


        // Continuous heading tracking with PD
        float heading = readHeadingSafe();
        float err = headingError(heading, targetHeading);


        unsigned long now = millis();
        float dt = (now - lastTime) * 0.001f; // seconds
        if (dt <= 0.0f) dt = 0.001f;


        float dErr = (err - lastError) / dt; // deg/s


        float wheelAngle = -(KP_HEADING * err + KD_HEADING * dErr);


        applySteering(wheelAngle);


        lastError = err;
        lastTime = now;


        // Status every ~900 ms
        if (now - lastPrint > 900) {
            char line0[24];
            sprintf(line0, "Edge %d", currentEdge + 1);
            char line1[30];
            sprintf(line1, "H=%.0f T=%.0f", heading, targetHeading);
            printStatus(line0, line1, heading);
            lastPrint = now;
        }


        delay(10);
    }


    driveMotor.brake();
    steerServo.write(SERVO_CENTER);
}


void driveAndTurnOnGaps() {
    // Start by holding the heading at which the robot was placed.
    targetHeading = snapHeading45(readHeadingSafe());

    int leftGapCount = 0;
    int rightGapCount = 0;

    int previousLeftDist = 0;
    int previousRightDist = 0;

    unsigned long lastTurnTime = 0;

    lastParkErr = 0.0f;
    lastParkTime = millis();

    driveMotor.run(DRIVE_SPEED);

    while (true) {
        // Read and smooth the sensors.
        int leftDist = leftGapFilter.update(tofLeft.getDistance());
        int rightDist = rightGapFilter.update(tofRight.getDistance());
        int frontDist = frontGapFilter.update(tofFront.getDistance());

        // Keep the vehicle travelling on targetHeading.
        headingDriveStep();

        // A gap can be detected by a far reading or a sudden increase.
        bool leftGapNow = leftDist > GAP_THRESHOLD_MM;
        bool rightGapNow = rightDist > GAP_THRESHOLD_MM;

        bool leftOpening = previousLeftDist > 0 &&
                           leftDist > previousLeftDist + 150;

        bool rightOpening = previousRightDist > 0 &&
                            rightDist > previousRightDist + 150;

        if (leftGapNow || leftOpening) {
            leftGapCount++;
        } else {
            leftGapCount = 0;
        }

        if (rightGapNow || rightOpening) {
            rightGapCount++;
        } else {
            rightGapCount = 0;
        }

        bool leftGapConfirmed = leftGapCount >= GAP_CONFIRM_SAMPLES;
        bool rightGapConfirmed = rightGapCount >= GAP_CONFIRM_SAMPLES;

        bool cooldownDone = millis() - lastTurnTime > TURN_COOLDOWN_MS;

        // Turn toward the confirmed gap.
        if (cooldownDone && (leftGapConfirmed || rightGapConfirmed)) {
            bool turnLeft = false;

            if (leftGapConfirmed && !rightGapConfirmed) {
                turnLeft = true;
            } else if (!leftGapConfirmed && rightGapConfirmed) {
                turnLeft = false;
            } else {
                // Both sides see an opening: use the larger clearance.
                turnLeft = leftDist > rightDist + GAP_DIRECTION_MARGIN_MM;
            }

            if (turnLeft) {
                targetHeading = snapHeading45(targetHeading - 90.0f);
            } else {
                targetHeading = snapHeading45(targetHeading + 90.0f);
            }

            leftGapCount = 0;
            rightGapCount = 0;
            lastTurnTime = millis();

            // Drive continuously and use IMU heading control until
            // the vehicle has completed the 90-degree turn.
            while (true) {
                float heading = readHeadingSafePark();
                float err = headingError(heading, targetHeading);

                headingDriveStep();

                int turnFrontDist = frontGapFilter.update(tofFront.getDistance());

                // Heading is close enough to the requested 90-degree direction.
                if (abs(err) < TURN_COMPLETE_ERROR) {
                    break;
                }

                // Optional safety stop if about to hit a front wall.
                if (turnFrontDist > 0 && turnFrontDist < 80) {
                    driveMotor.brake();
                    delay(150);
                    driveMotor.run(DRIVE_SPEED);
                }

                delay(10);
            }

            // Continue forward after turning so that the same intersection
            // cannot immediately trigger another side-gap turn.
            long clearStartAngle = driveMotor.getAngle();

            while (labs(driveMotor.getAngle() - clearStartAngle) <
                   POST_TURN_DISTANCE) {

                headingDriveStep();

                delay(10);
            }

            // Reset confirmation counts after leaving the junction.
            leftGapCount = 0;
            rightGapCount = 0;
        }

        // Display useful live values.
        evo.clearDisplay();

        evo.writeToDisplay("L:", 0, 0);
        evo.writeToDisplay(leftDist, 16, 0);

        evo.writeToDisplay("R:", 62, 0);
        evo.writeToDisplay(rightDist, 78, 0);

        evo.writeToDisplay("F:", 0, 16);
        evo.writeToDisplay(frontDist, 16, 16);

        evo.writeToDisplay("H:", 62, 16);
        evo.writeToDisplay((int)readHeadingSafe(), 78, 16);

        evo.writeToDisplay("T:", 0, 32);
        evo.writeToDisplay((int)targetHeading, 16, 32);

        evo.drawDisplay();

        previousLeftDist = leftDist;
        previousRightDist = rightDist;

        delay(10);
    }
}
// ---------- Main behaviour: single-phase square with PD steering ----------


void setup() {
    evo.begin();
    tofRight.begin();
    tofBack.begin();
    tofLeft.begin();
    tofFront.begin();
    bno.begin();

    // IMU init with a basic check
    evo.clearDisplay();
    evo.writeLineToDisplay("Init IMU...", 0, true, true);
    evo.drawDisplay();



    evo.playTone(1000,10,false);
    delay(1000);


    // Take one good reading to seed lastValidHeading and targetHeading
    float x, y, z;
    bno.getEuler(&x, &y, &z);
    if (!isnan(x) && !isinf(x) && x >= 0 && x < 360) {
    lastValidHeading = normalize(x);
    } else {
    lastValidHeading = 0.0f; // safe default
    }


    driveMotor.begin();
    steerServo.begin();


    steerServo.write(SERVO_CENTER);
    evo.writeLineToDisplay("Setup done", 0, true, true);
    evo.drawDisplay();
    driveMotor.resetAngle();
    //driveMotor.runAngle(4000,500);
    // parallelParkWithTOF();
    //squareWithPDSteering(4);
    driveAndTurnOnGaps();
    steerServo.write(SERVO_CENTER);
}

void loop() {
    // one-shot run in setup()
    //evo.writeToDisplay(tofFront.getDistance(), 0, 0);
    //evo.drawDisplay();
    //evo.writeLineToDisplay(tofFront.getDistance(), 1, true, false);
    //evo.writeLineToDisplay(tofLeft.getDistance(), 2, false, false);
    //evo.writeLineToDisplay(tofRight.getDistance(), 3, false, false);
    //evo.writeLineToDisplay(tofBack.getDistance(), 4, false, false);
    //evo.drawDisplay();
    //delay(10);
}

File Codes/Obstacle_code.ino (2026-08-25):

#include "Evo.h"

// ------------------------------------------------------------
// Hardware setup
// ------------------------------------------------------------
EVOX1 evo;

EvoIMU bno(I2C1);

EvoTOF tofRight(I2C2);
EvoTOF tofBack(I2C5);
EvoTOF tofLeft(I2C3);
EvoTOF tofFront(I2C4);

EvoMotor driveMotor(M1, EVOMotor300, true);
EvoServo steerServo(SERVO1, GeekServo360Grey);

// ------------------------------------------------------------
// Motion settings
// ------------------------------------------------------------
const int DRIVE_SPEED = 3000;

const float SERVO_RATIO = 2.33f;
const int SERVO_CENTER = 180;
const int MAX_WHEEL_ANGLE = 35;

const float KP_HEADING = 1.4f;
const float KD_HEADING = 0.0f;

// ------------------------------------------------------------
// Gap detection settings
// ------------------------------------------------------------
const int GAP_THRESHOLD_MM = 500;
const int GAP_CONFIRM_SAMPLES = 4;
const int GAP_DIRECTION_MARGIN_MM = 100;

const long POST_TURN_DISTANCE = 1000;
const unsigned long TURN_COOLDOWN_MS = 700;
const int TURN_COMPLETE_ERROR = 3;
const int FRONT_EMERGENCY_MM = 80;

// ------------------------------------------------------------
// MaixCAM detection settings
//
// Change class IDs to match your YOLO model labels.
// ------------------------------------------------------------
const int GREEN_ID = 1;
const int RED_ID = 2;

const int MIN_COLOR_AREA = 100;
const float MIN_COLOR_CONFIDENCE = 0.50f;

// MaixCAM image-space limit. Lower image areas represent nearby
// obstacles if camera y increases downward.
const int MAX_COLOR_Y_CENTER = 160;

const float COLOR_AVOID_ANGLE = 45.0f;

// Minimum encoder travel while avoiding the coloured object.
const long COLOR_MIN_OUTWARD_DISTANCE = 500;

// The object must be missing for this long before crossing back.
const unsigned long COLOR_LOST_TIMEOUT_MS = 350;

// Prevent repeat detection of the same object immediately afterward.
const unsigned long COLOR_RETRIGGER_COOLDOWN_MS = 1000;

// ------------------------------------------------------------
// MaixCAM packet sent by:
// struct.pack("<hhHHHf", x, y, w, h, classID, confidence)
//
// Packed ensures the structure has exactly 14 bytes.
// ------------------------------------------------------------
struct __attribute__((packed)) MaixObject {
    int16_t x;
    int16_t y;
    uint16_t width;
    uint16_t height;
    uint16_t classID;
    float confidence;
};

const int MAIX_PACKET_BYTES = sizeof(MaixObject);

// ------------------------------------------------------------
// Colour avoidance state
// ------------------------------------------------------------
enum ColourState {
    COLOR_NONE,
    COLOR_TURN_OUT,
    COLOR_DRIVE_OUT,
    COLOR_TURN_BACK,
    COLOR_DRIVE_BACK,
    COLOR_RETURN_HEADING
};

ColourState colourState = COLOR_NONE;

int colourDirection = 0;       // -1 = green/left, +1 = red/right
float headingBeforeColour = 0.0f;

long colourOutwardStartAngle = 0;
long colourOutwardDistance = 0;
long colourReturnStartAngle = 0;

unsigned long lastColourSeenTime = 0;
unsigned long lastColourActionTime = 0;

// ------------------------------------------------------------
// Heading state
// ------------------------------------------------------------
float targetHeading = 0.0f;
float lastValidHeading = 0.0f;

float lastParkErr = 0.0f;
unsigned long lastParkTime = 0;

// ------------------------------------------------------------
// Heading functions
// ------------------------------------------------------------
float normalize(float a) {
    while (a < 0.0f) a += 360.0f;
    while (a >= 360.0f) a -= 360.0f;
    return a;
}

float headingError(float current, float target) {
    float e = target - current;

    if (e > 180.0f) e -= 360.0f;
    if (e < -180.0f) e += 360.0f;

    return e;
}

float snapHeading45(float a) {
    a = normalize(a);
    int k = (int)((a + 22.5f) / 45.0f);
    return normalize((float)(k * 45));
}

float readHeadingSafe() {
    float x, y, z;

    bno.getEuler(&x, &y, &z);

    if (!isnan(x) && !isinf(x) && x >= 0.0f && x < 360.0f) {
        lastValidHeading = normalize(x);
        return lastValidHeading;
    }

    delay(2);

    bno.getEuler(&x, &y, &z);

    if (!isnan(x) && !isinf(x) && x >= 0.0f && x < 360.0f) {
        lastValidHeading = normalize(x);
        return lastValidHeading;
    }

    return lastValidHeading;
}

float readHeadingSafePark() {
    return readHeadingSafe();
}

// ------------------------------------------------------------
// Steering functions
// ------------------------------------------------------------
void applySteering(float wheelAngle) {
    wheelAngle = constrain(wheelAngle, -MAX_WHEEL_ANGLE, MAX_WHEEL_ANGLE);

    float servoCmd = SERVO_CENTER + wheelAngle * SERVO_RATIO;
    servoCmd = constrain(servoCmd, 0, 360);

    steerServo.write((int)servoCmd);
}

void headingDriveStep() {
    float heading = readHeadingSafePark();
    float err = headingError(heading, targetHeading);

    unsigned long now = millis();
    float dt = (now - lastParkTime) * 0.001f;

    if (dt <= 0.0f) {
        dt = 0.001f;
    }

    float dErr = (err - lastParkErr) / dt;

    float wheelAngle = -(KP_HEADING * err + KD_HEADING * dErr);

    applySteering(wheelAngle);

    lastParkErr = err;
    lastParkTime = now;
}

// ------------------------------------------------------------
// MaixCAM I2C receiver
//
// IMPORTANT:
// EVOX1 must be configured as an I2C slave at address 0x24
// on an unused I2C bus. Do not share I2C5 because it is already
// used by tofBack.
//
// The missing implementation is library-specific. Insert the
// callback/buffer implementation required by your EVOX1 I2C API.
// ------------------------------------------------------------
bool readMaixObject(MaixObject &obj) {
    // Example intended behaviour:
    //
    // if (maixI2CSlave.available() >= MAIX_PACKET_BYTES) {
    //     maixI2CSlave.readBytes((uint8_t*)&obj, MAIX_PACKET_BYTES);
    //     return true;
    // }
    //
    // return false;

    return false;
}

// ------------------------------------------------------------
// MaixCAM object validation
// ------------------------------------------------------------
bool isValidColourObject(const MaixObject &obj) {
    if (obj.classID != RED_ID && obj.classID != GREEN_ID) {
        return false;
    }

    int objectArea = (int)obj.width * (int)obj.height;

    if (objectArea < MIN_COLOR_AREA) {
        return false;
    }

    if (obj.confidence < MIN_COLOR_CONFIDENCE) {
        return false;
    }

    int yCenter = obj.y + ((int)obj.height / 2);

    if (yCenter > MAX_COLOR_Y_CENTER) {
        return false;
    }

    return true;
}

bool getColourDetection(MaixObject &obj) {
    if (!readMaixObject(obj)) {
        return false;
    }

    return isValidColourObject(obj);
}
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

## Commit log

2026-08-21 Added models
    [EVO Brick Model.stl, VL53L0X Lego Mount Model.stl]
2026-08-21 Added unused stl files
    [weird_5_hole.stl, weird_axel_thingy.stl]
2026-08-21 Rename 041EC766-B85B-45DE-ABB6-07EABB48EC1A_1_105_c.jpeg to Image of Second prototype 4WD 4 wheel steering Chassis
2026-08-21 Rename 14D7B0CD-A85A-4893-8576-EC185C0AA9C7_1_105_c.jpeg to Underside of first prototype chassis
2026-08-21 Rename 2DA200FB-7B0C-4081-B9E4-5D6E7777646C_4_5005_c.jpeg to Front of upgraded first prototype chassis
2026-08-21 Rename 31DF0EC9-3BA1-462B-B613-45BC8223A1CB_4_5005_c.jpeg to Left side of upgraded first prototype chassis
2026-08-21 Add README for first prototype images
2026-08-24 Create Open_Code
    Added functionality for square movement using PD steering with improved heading control and safety measures for reading IMU data.
2026-08-25 Fix formatting in README.md for prototype section
2026-08-25 Implement I2C communication for object detection results
2026-08-25 Fix typo in I2C communication comment and update README for repository structure and content
2026-08-25 Add main navigation logic for robot with sensors
    This file implements the main navigation logic for a robot using various sensors and motors. It includes hardware setup, motion settings, gap detection, and steering control functionalities.
2026-08-25 Add Obstacle avoidance code for EVOX1
    [Obstacle_code.ino]
